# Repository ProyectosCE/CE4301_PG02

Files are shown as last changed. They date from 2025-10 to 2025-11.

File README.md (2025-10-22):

# Instituto Tecnológico de Costa Rica

## Proyecto Grupal 2

### Robot basado en microcontrolador  

#### Arquitectura de Computadores I (CE4301)

---

### Estudiantes

* José Bernardo Barquero Bonilla (2023150476)
* Jose Eduardo Campos Salazar (2023135620)
* Jimmy Feng Feng (2023060347)
* Alexander Montero Vargas (2023166058)

### Profesor

* Dr.-Ing. Jeferson González Gómez — *[jgonzalez@itcr.ac.cr](mailto:jgonzalez@itcr.ac.cr)*

---

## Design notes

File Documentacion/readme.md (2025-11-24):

# **GimmiCoin – Alcancía Inteligente (Proyecto CE4301)**
## *Robot basado en microcontrolador – Arquitectura de Computadores I*

GimmiCoin es un robot–alcancía que detecta monedas por contacto metálico, pesa cada moneda para clasificarla, reproduce un sonido y registra el total acumulado.  
Ofrece una interfaz web embebida accesible desde cualquier teléfono mediante WiFi.

---

# **1. Propósito del Proyecto**
Este proyecto implementa un sistema embebido basado en microcontrolador que permite registrar monedas mediante:

- **Detección por contacto metálico** (flanco limpio y confiable).  
- **Pesaje preciso** mediante celda de carga + HX711.  
- **Movimiento mecánico** mediante motor DC para despejar la bandeja.  
- **Reproducción de audio** con DFPlayer Mini + parlante.  
- **Persistencia** del total mediante EEPROM.  
- **Interfaz web** en modo Access Point con página principal y panel administrativo.

El diseño físico utiliza el personaje Pokémon **Gimmighoul**, integrando electrónica, mecánica y software embebido.

---

# **2. Arquitectura General del Sistema**

Moneda → Sensor de contacto → FSM → Pesaje (HX711)
→ Motor DC (limpieza) → DFPlayer (audio)
→ EEPROM (contador) → WiFi AP → Interfaz Web

El sistema opera como access point (`SoftAP`), donde cualquier smartphone puede conectarse a la red creada por el dispositivo, visualizar el total y gestionar la alcancía.

---

# **3. Hardware Utilizado**

## 3.1 **Componentes principales**
- **Microcontrolador:** ESP8266 (D1 Mini).  
- **Sensor de moneda:** contacto metálico (pull-down externo de 10 kΩ).  
- **Pesaje:** celda de carga TAL221 + amplificador HX711.  
- **Actuador:** motor DC controlado por transistor 2N2222 + diodo flyback.  
- **Audio:** DFPlayer Mini + parlante 8Ω 0.5 W.  
- **Alimentación:** powerbank 5V.  
- **Tarjeta perforada:** montaje final obligatorio.

## 3.2 **Conexiones (resumen)**
- Sensor moneda → `D2`  
- HX711 DT / SCK → `D5 / D6`  
- Motor DC → `D8`  
- DFPlayer Mini → `D3 (TX)` y `D4 (RX con resistencia serie 1 kΩ)`  
- Powerbank 5V → Motor + DFPlayer + regulador interno 3.3V para ESP8266  

---

# **4. Diagrama Eléctrico**

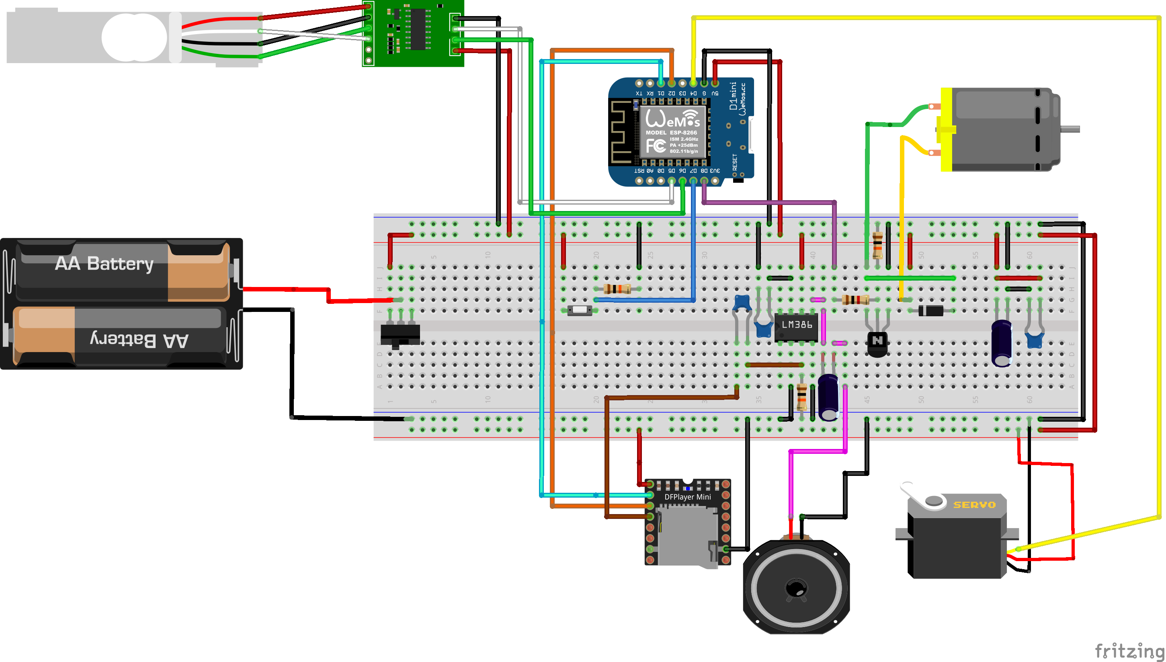
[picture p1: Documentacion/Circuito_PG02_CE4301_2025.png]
Diagrama eléctrico


---

# **5. Máquina de Estados (FSM)**

```mermaid
stateDiagram-v2
    [*] --> DeepSleep

    state "Deep Sleep" as DeepSleep
    state "Wake / Init" as WakeInit
    state "Detección de moneda" as Detect
    state "Pesaje (HX711)" as Weigh
    state "Acciones (motor / audio)" as Actions
    state "Actualizar EEPROM" as UpdateEEPROM
    state "Esperar otra moneda" as WaitCoin
    state "Pre-sleep" as PreSleep

    DeepSleep --> WakeInit: Flanco sensor contacto\n(reset / wakeup)
    WakeInit --> Detect: Init balanza / DFPlayer /\nrestaurar contador
    Detect --> Weigh: Moneda validada
    Weigh --> Actions: Peso estable y válido
    Actions --> UpdateEEPROM: Acción completada
    UpdateEEPROM --> WaitCoin: Guardar total si corresponde

    WaitCoin --> Detect: Nueva moneda antes de timeout
    WaitCoin --> PreSleep: Timeout sin monedas

    PreSleep --> DeepSleep: Preparar deep sleep\n(guardar estado mínimo)

```

---

# **6. Persistencia**

* El total acumulado se almacena en EEPROM.
* Se escribe solo después de un **timeout de 12 s** para evitar desgaste.
* En reinicio o wake del deep sleep, el sistema restaura el total anterior.

---

# **7. Interfaz Web (HTTP sobre WiFi AP)**

## Red generada por el robot:

* **SSID:** `GimmiCoin_AP`
* **Password:** `12345678`
* **IP:** `192.168.4.1`

## Endpoints

| Ruta | Método | Autenticación | Función |
| --- | --- | --- | --- |
| `/` | GET | No | Página principal con total |
| `/estado` | GET | No | JSON con total y estado |
| `/admin`  | GET | Sí | Panel administrativo |
| `/reset`  | GET | Sí | Reinicia contador |

Ejemplo `/estado`:

```json
{
  "total_crc": 350,
  "peso_ultimo": 10.1,
  "moneda_valida": true
}
```

---

# **8. Compilación y Ejecución**

## 8.1 **Requisitos**

Instalar en Arduino IDE / PlatformIO:

* ESP8266 Core
* Librerías:

  * `ESP8266WiFi.h`
  * `ESP8266WebServer.h`
  * `EEPROM.h`
  * `SoftwareSerial.h`
  * `DFRobotDFPlayerMini.h`
  * `HX711.h`

## 8.2 **Configuración**

* Placa: **Wemos D1 Mini**
* Velocidad: **80 MHz**
* Flash size: **4 MB (FS: 1 MB)**
* Baud: **115200**

## 8.3 **Ejecución**

1. Conectar la D1 mini por USB.
2. Seleccionar placa + puerto.
3. Subir firmware.
4. Desconectar USB → alimentar desde powerbank.
5. Conectarse al AP WiFi y abrir:
   [https://192.168.4.1](https://192.168.4.1)

---

# **9. Montaje Mecánico**

* Cuerpo construido como Gimmighoul.
* Bandeja de pesaje alineada con la celda TAL221.
* Motor DC fijo en canal de expulsión.
* Sensor de contacto ubicado en entrada de moneda.
* Placa perforada montada en compartimento seguro.

---

# **10. Lista de Materiales (BOM resumida)**

> Ver archivo completo en `docs/BOM.md`.

| Categoría | Componentes |
| --- | --- |
| MCU | D1 Mini ESP8266 |
| Sensores | Celda TAL221, HX711, sensor de contacto |
| Actuadores | Motor DC + 2N2222 + diodo 1N4148 |
| Audio | DFPlayer Mini + parlante |
| Alimentación | Powerbank 5V |
| Estructura | Materiales 3D o reciclados |
| Otros | Resistencias, cables, placa perforada |

---

# **11. Pruebas Realizadas**

* Pruebas de detección (sensor contacto vs rebotes).
* Pruebas de pesaje y calibración.
* Pruebas motor–expulsión.
* Pruebas audio DFPlayer.
* Pruebas de integración FSM completa.
* Pruebas de interfaz web.
* Pruebas de funcionamiento alimentado por powerbank.

---

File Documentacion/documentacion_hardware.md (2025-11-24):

# Diseño de Hardware – GimmiCoin (Alcancía Inteligente)

## 1. Selección y Justificación del Microcontrolador

El sistema GimmiCoin está basado en el **SoC ESP8266**, utilizando el módulo **D1 Mini** como plataforma de integración. La elección de este microcontrolador se justifica por las siguientes razones:

- **Conectividad Wi-Fi integrada:** permite implementar un servidor web embebido y operar en modo *Access Point* sin hardware adicional de red.
- **Capacidad de cómputo adecuada:** el ESP8266 ofrece recursos suficientes para:
  - Manejar interrupciones del sensor de moneda.
  - Leer y filtrar datos del módulo **HX711**.
  - Controlar el **motor DC** para la limpieza de monedas.
  - Gestionar la comunicación HTTP con la interfaz web.
- **Ecosistema maduro de librerías:** existen librerías probadas para:
  - Servidor web (`ESP8266WebServer`).
  - Manejo de EEPROM.
  - Integración con el módulo **HX711**.
  - Control del módulo de audio **DFPlayer Mini**.
- **Factor de forma compacto:** el D1 Mini tiene un tamaño reducido, lo cual facilita su integración dentro de la estructura física del personaje Gimmighoul.
- **Regulación de 3.3 V integrada:** el propio módulo incorpora regulación a 3.3 V desde 5 V, simplificando el diseño de alimentación cuando se usa una *powerbank* como fuente.

En el montaje final sobre **tarjeta perforada**, se replica el esquema de conexiones del D1 Mini con el resto de componentes, respetando niveles lógicos de 3.3 V y una distribución física adecuada para minimizar ruido y cableado excesivo.

---

## 2. Diagrama Eléctrico General del Sistema

El circuito completo del sistema se modeló y verificó en **Fritzing**. A continuación se muestra el diagrama eléctrico utilizado como referencia para el montaje en tarjeta perforada:

Diagrama eléctrico del sistema

---

## 3. Sensores y Estrategia de Medición

### 3.1 Sensor de Moneda por Contacto

Para la detección básica de la inserción de una moneda se utiliza un **sensor de contacto metálico**:

* Implementado como un par de conductores metálicos que se cierran cuando la moneda pasa por el canal de entrada.
* Un extremo se conecta a **Vcc** (a través de adecuadas resistencias si se requiere) y el otro al pin digital configurado con un **pull-down** externo de 10 kΩ.
* El pin del ESP8266 (por ejemplo **D2**) se configura como entrada digital, leyendo un flanco limpio (paso de **NO contacto → contacto**) que dispara la lógica de conteo y pesaje.
* La detección se complementa con lógica de *debounce* por tiempo en firmware para evitar múltiples detecciones por una misma moneda.

Este sensor permite un disparo confiable del flujo de la FSM sin requerir sensores ópticos adicionales.

### 3.2 Celda de Carga TAL221 + HX711

La **celda de carga TAL221 (100 g)** se utiliza para obtener el peso de la moneda y con ello inferir su denominación:

* La celda funciona como un puente de Wheatstone de 4 hilos, que se conecta al módulo **HX711**.
* El HX711 amplifica la señal analógica de la celda y la convierte a digital mediante un ADC de 24 bits.
* Conexión típica al ESP8266:

  * `DT` → pin digital (ej. **D5**).
  * `SCK` → pin digital (ej. **D6**).
  * `VCC` → 3.3 V.
  * `GND` → GND común.
* En firmware se realiza:

  * Secuencia de *tare* al iniciar el sistema (con la balanza vacía).
  * Lectura de múltiples muestras y promediado para obtener un peso estable.
  * Comparación del peso con rangos predefinidos para clasificar el tipo de moneda (p. ej. ~2.2 g, ~3.5 g, ~7.0 g, ~10.1 g).

Esta estrategia permite distinguir monedas con diámetros similares pero pesos diferentes, mejorando la confiabilidad en la clasificación.

---

## 4. Actuadores y Etapa de Potencia

### 4.1 Motor DC para Limpieza de Monedas

El sistema emplea un **motor DC** como único actuador mecánico para:

* Desplazar la moneda fuera de la zona de pesaje una vez completida la lectura de peso.
* Evitar acumulación de monedas sobre la celda, lo que podría causar errores de medición.

El motor se controla mediante un **transistor NPN 2N2222** en configuración de conmutación:

* **Base**: conectada a un pin digital (por ejemplo **D8**) mediante una resistencia en serie (ej. 1 kΩ).
* **Colector**: al terminal negativo del motor.
* **Emisor**: a GND.
* El terminal positivo del motor se conecta directamente a la línea de **5 V** de la powerbank.
* En paralelo con el motor se coloca un **diodo flyback** (ej. 1N4148 o 1N4007) para proteger contra picos de tensión inducidos al apagar el motor.

Este arreglo forma una etapa de potencia sencilla y adecuada para el consumo típico del motor, aprovechando la capacidad de corriente de la powerbank.

---

## 5. Módulo de Audio: DFPlayer Mini + Parlante

Para la retroalimentación sonora al usuario se utiliza un **DFPlayer Mini**, controlado desde el ESP8266:

* Comunicación mediante UART:

  * `TX` del ESP8266 → `RX` del DFPlayer (a través de una **resistencia serie de 1 kΩ** para adaptar niveles y proteger la entrada).
  * `RX` del ESP8266 → `TX` del DFPlayer (según diseño y disponibilidad de pines).
* Alimentación:

  * `VCC` → 5 V (desde la powerbank).
  * `GND` → GND común.
* El módulo se conecta a un **parlante de 8 Ω / 0.5 W**, suficiente para reproducir efectos de sonido al registrar monedas.

---

## 6. Alimentación y Distribución de Energía

La alimentación del sistema se basa en una **powerbank de 5 V**:

* El **D1 Mini** integra un regulador a 3.3 V, por lo que puede alimentarse directamente desde los 5 V de la powerbank.
* El motor DC y el DFPlayer Mini se alimentan también desde la línea de **5 V**.
* El módulo HX711 se alimenta desde la línea de **3.3 V** del D1 Mini, compartiendo GND común.

---

## 7. Consumo Energético Estimado

El consumo estimado de cada bloque es:

| Componente | Consumo aproximado |
| --- | --- |
| ESP8266 (D1 Mini) | 70–200 mA (según WiFi y carga) |
| HX711 + celda de carga | ~10 mA |
| DFPlayer Mini + parlante | 40–100 mA (según volumen) |
| Motor DC | 150–300 mA (ráfagas cortas) |

En operación típica, el consumo promedio se mantiene dentro de la capacidad de salida de una powerbank estándar (5 V, 2–3 A), permitiendo sesiones prolongadas de uso. La activación del motor DC ocurre solo durante breves intervalos después de cada moneda, lo que reduce su impacto en el consumo medio.

---

## 8. Tarjeta Perforada y Organización Física

Todo el circuito se implementa sobre una **tarjeta perforada** en la versión final del proyecto, cumpliendo con la especificación del curso:

* Se ubican el D1 Mini, el módulo HX711, el transistor 2N2222, el diodo flyback, las resistencias y conectores hacia el motor, sensor de contacto, DFPlayer y parlante.
* Se organizan las pistas de alimentación (5 V y GND) en rieles bien definidos para reducir la cantidad de cables sueltos.
* Las señales sensibles (DT/SCK del HX711 y la línea del sensor de contacto) se mantienen separadas del cableado del motor para minimizar el ruido.
* Se utilizan conectores o headers desmontables para facilitar el montaje y mantenimiento dentro de la estructura del Gimmighoul.

---

## 9. Consideraciones de Diseño Mecánico

El chasis del proyecto se basa en la estética del personaje **Gimmighoul**:

* La **bandeja de pesaje** se monta rígidamente sobre la celda TAL221, de forma que solo las fuerzas verticales de la moneda sean transmitidas a la celda.
* El **motor DC** y su mecanismo (por ejemplo, una paleta/plataforma que empuja la moneda) se alinean con la salida de la bandeja para que todas las monedas abandonen la zona de medición.
* El **sensor de contacto** se ubica en la entrada de monedas, garantizando que cualquier moneda deba cerrar el circuito para ser detectada.
* Se reserva un compartimento aislado para:

  * Powerbank.
  * Tarjeta perforada.
  * Cableado.
  * DFPlayer y parlante.
* Se evita el contacto directo de las monedas con la electrónica para prevenir cortocircuitos y daños por suciedad o humedad.

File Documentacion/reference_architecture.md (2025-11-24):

# Arquitectura de Referencia – GimmiCoin (Gimmighoul Coin Collector)

---

## 1. Resumen del Sistema

GimmiCoin es una **alcancía inteligente** basada en un microcontrolador **ESP8266 (D1 Mini)** que:

1. Detecta monedas mediante un **sensor de contacto metálico**.
2. Pesa la moneda usando una **celda de carga TAL221 + módulo HX711**.
3. Acciona un **motor DC** para desplazar la moneda fuera de la bandeja de pesaje.
4. Reproduce un sonido con un **DFPlayer Mini** + parlante.
5. Actualiza un **contador total** almacenado en EEPROM.
6. Expone el estado mediante una **aplicación web** servida por el ESP8266 en modo **Access Point (AP)**.

La arquitectura de referencia define cómo se organizan estos componentes de hardware y software, así como los flujos principales y las interfaces entre ellos.

---

## 2. Objetivos Arquitectónicos

Los principales objetivos de diseño son:

- **Simplicidad y robustez:** Minimizar la cantidad de actuadores y sensores mecánicamente complejos. Se usa un solo motor DC y un sensor de contacto simple.
- **Medición confiable:** Usar **peso** en lugar de geometría para distinguir monedas con diámetros similares.
- **Bajo acoplamiento:** Separar hardware, firmware y aplicación web en módulos bien definidos.
- **Escalabilidad:** Permitir futuras mejoras (clasificación por tipo de moneda, más vistas en la app, integración con backend externo).
- **Trazabilidad ágil:** Mantener una arquitectura que se refleje directamente en el **Product Backlog**, la **Definition of Done (DoD)** y el **Risk Assessment**.

---

## 3. Arquitectura de Hardware (Vista de Bloques)

### 3.1 Diagrama de bloques de hardware

```mermaid
flowchart LR
    subgraph PWR[Alimentación]
        PB[Powerbank 5V]
    end

    subgraph MCU[D1 Mini – ESP8266]
        CPU[Firmware FSM<br/>WiFi AP + HTTP]
        MEM[EEPROM / Flash<br/>contador total]
    end

    SC[Sensor de contacto<br/>moneda]
    LC[Celda de carga TAL221<br/>100 g]
    HX[HX711<br/>ADC 24 bits]
    MOT[Motor DC<br/>desplazamiento moneda]
    NPN[2N2222 + diodo<br/>etapa de potencia]
    DF[DFPlayer Mini]
    SPK[Parlante 8Ω 0.5W]

    %% Conexiones de señal
    SC -->|GPIO digital| MCU
    LC --- HX
    HX -->|DT, SCK| MCU
    MCU -->|GPIO| NPN
    NPN --> MOT
    MCU <-->|UART| DF
    DF --- SPK

    %% Alimentación
    PB -->|5V| MCU
    PB -->|5V| MOT
    PB -->|5V| DF
```

### 3.2 Justificación de decisiones de hardware

* **Powerbank 5 V:**
  Simplifica la alimentación (no se requiere etapa LiPo + cargador + boost/buck separados). Además, las powerbanks son fáciles de recargar y proporcionan corriente suficiente para el motor y DFPlayer.

* **Sensor de contacto:**
  Es una solución simple y confiable para detectar el paso de monedas, sin necesidad de sensor IR ni óptico. Facilita el montaje mecánico y reduce costos.

* **Celda de carga + HX711:**
  Permite diferenciar monedas por peso con buena resolución. El HX711 provee una interfaz digital síncrona sencilla de manejar desde el ESP8266.

* **Motor DC + 2N2222:**
  Un solo actuador mecánico es suficiente para despejar la bandeja. La etapa de potencia con 2N2222 + diodo flyback es una solución estándar y robusta.

* **DFPlayer Mini + parlante:**
  Descentraliza el manejo de audio (el ESP8266 solo envía comandos por UART), reduciendo la carga de procesamiento y memoria del microcontrolador.

---

## 4. Arquitectura del Software Embebido

La arquitectura de software se organiza en tres capas principales:

1. **Drivers / HAL (Hardware Abstraction Layer)**
2. **Servicios de dominio (lógica de GimmiCoin)**
3. **Capa de aplicación y comunicación (FSM + HTTP)**

### 4.1 Diagrama de capas de software

```mermaid
flowchart TD
    subgraph APP[Capa de Aplicación]
        FSM[FSM de GimmiCoin<br/>DeepSleep, Detect, Weigh,<br/>Actions, UpdateEEPROM, Wait, PreSleep]
        HTTP[Servidor HTTP<br/>/ /estado /admin /reset]
    end

    subgraph SRV[Servicios]
        DET[Servicio de detección de moneda]
        WEI[Servicio de pesaje y filtrado]
        ACT[Servicio de acciones<br/>motor + audio]
        PERS[Servicio de persistencia<br/>EEPROM]
        NET[Servicio de red<br/>WiFi AP]
    end

    subgraph DRV[Drivers / HAL]
        D_GPIO[Driver GPIO<br/>sensor, motor]
        D_HX[Driver HX711]
        D_DFP[Driver DFPlayer]
        D_EE[Driver EEPROM]
        D_WIFI[Driver WiFi / TCP]
    end

    FSM --> DET
    FSM --> WEI
    FSM --> ACT
    FSM --> PERS
    HTTP --> NET
    DET --> D_GPIO
    WEI --> D_HX
    ACT --> D_GPIO
    ACT --> D_DFP
    PERS --> D_EE
    NET --> D_WIFI
```

### 4.2 Relación con módulos `.ino`

* `GimmiCoin_Main.ino` → FSM + inicialización.
* `GimmiCoin_SensorMoneda.ino` → parte de **DET + D_GPIO**.
* `GimmiCoin_Balanza.ino` → **WEI + D_HX**.
* `GimmiCoin_Motor.ino` → **ACT + D_GPIO**.
* `GimmiCoin_Sonido.ino` → **ACT + D_DFP**.
* `GimmiCoin_Memoria.ino` → **PERS + D_EE**.
* `GimmiCoin_Web.ino` → **HTTP + NET + D_WIFI**.

Este mapeo permite vincular directamente el **Product Backlog** con componentes arquitectónicos concretos (por ejemplo, historias de usuario para el servicio de pesaje, o para la interfaz web).

---

## 5. Arquitectura de Comunicación y Aplicación Web

El modelo de comunicación es **cliente–servidor** sobre HTTP dentro de una red local creada por el propio robot.

### 5.1 Diagrama de bloques de comunicación

```mermaid
flowchart TD
    C[Teléfono / Laptop<br/> Cliente Web] <--> S[ESP8266<br/>AP + Servidor HTTP]

    S --> H[HTML - Página principal<br/>GET /]
    S --> J[JSON de estado<br/>GET /estado]
    S --> A[Panel admin<br/>GET /admin]
    S --> R[Comando RESET<br/>GET /reset]
```

### 5.2 Diagrama de secuencia – Lectura de estado

```mermaid
sequenceDiagram
    participant User as Cliente Web
    participant HTTP as ESP8266 HTTP
    participant FSM as FSM / Servicios

    User->>HTTP: GET /estado
    HTTP->>FSM: Solicitar estado actual
    FSM-->>HTTP: total_crc, peso_ultimo, moneda_valida
    HTTP-->>User: JSON { total_crc, peso_ultimo, moneda_valida }
    User->>User: Refresca UI
```

### 5.3 Diagrama de secuencia – Reset desde el panel admin

```mermaid
sequenceDiagram
    participant Admin as Cliente (Admin)
    participant HTTP as ESP8266 HTTP
    participant MEM as EEPROM / Persistencia

    Admin->>HTTP: GET /reset (Basic Auth)
    HTTP->>MEM: Escribir total_crc = 0
    MEM-->>HTTP: Confirmación de escritura
    HTTP-->>Admin: JSON { "status": "ok", "reset": true }
```

---

## 6. Máquina de Estados de Alto Nivel (FSM)

La FSM coordina el comportamiento global del sistema, integrando sensores, acciones, persistencia y deep sleep.

```mermaid
stateDiagram-v2
    [*] --> DeepSleep

    state "Deep Sleep" as DeepSleep
    state "Wake / Init" as WakeInit
    state "Detección de moneda" as Detect
    state "Pesaje (HX711)" as Weigh
    state "Acciones (motor / audio)" as Actions
    state "Actualizar EEPROM" as UpdateEEPROM
    state "Esperar otra moneda" as WaitCoin
    state "Pre-sleep" as PreSleep

    DeepSleep --> WakeInit: Wake por sensor / reset
    WakeInit --> Detect: Init pines / HX711 /\nDFPlayer / WiFi AP
    Detect --> Weigh: Moneda detectada\n(bandera ISR)
    Weigh --> Actions: Peso estable\ny moneda válida
    Actions --> UpdateEEPROM: Motor + sonido OK
    UpdateEEPROM --> WaitCoin: Guardar total\n(si timeout cumplido)

    WaitCoin --> Detect: Nueva moneda\nantes del timeout
    WaitCoin --> PreSleep: Sin monedas\npor T_TIMEOUT

    PreSleep --> DeepSleep: Guardar estado mínimo\n+ entrar a deep sleep
```

---

## 7. Relación con Metodología Ágil

La arquitectura de referencia sirvió como base para:

* **Product Backlog:**

  * Historias de usuario ligadas a bloques arquitectónicos:

    * HU: “Como usuario quiero ver el total ahorrado en mi teléfono” → módulo HTTP + servicios NET + PERS.
    * HU: “Como usuario quiero que la alcancía reconozca monedas automáticamente” → DET + WEI + FSM.
    * HU: “Como administrador quiero resetear el contador” → HTTP `/admin` + `/reset` + PERS.

* **Definition of Done (DoD):**

  * Cada historia de usuario se considera terminada cuando:

    * Está integrada en la FSM y en el bloque arquitectónico correspondiente.
    * Se verifican pruebas unitarias/integración sobre las rutas HTTP, pesaje, detección y motor.

* **Risk Assessment:**

  * Los riesgos críticos (por ejemplo, calibración de peso, ruido eléctrico, integración física) se mapean a componentes:

    * R9 (calibración) → bloque WEI + D_HX.
    * R2 (alimentación) → bloque PWR + MOT + DFPlayer.
    * R7 (integración física) → interacción entre hardware mecánico (LC, MOT) y comp. electrónicos.

* **Planificación por Sprints:**

  * Sprint 1: Sensado de moneda (DET), prototipo de pesaje (WEI) y servidor web mínimo.
  * Sprint 2: FSM completa, integración motor + DFPlayer (ACT).
  * Sprint 3: Deep sleep, refinamiento de UI y calibración de peso.
  * Sprint 4: Pruebas finales, documentación y video de demostración.

De esta forma, la arquitectura no es solo un diagrama estático, sino una **guía para el desarrollo ágil**, que permite priorizar, estimar esfuerzo y evaluar el progreso de forma continua.

---

## 8. Seguridad y Robustez

La arquitectura contempló desde el inicio aspectos de:

* **Seguridad eléctrica:**

  * Uso de diodo flyback en motor.
  * Desacoplo en 5 V y 3.3 V.
  * GND común y rutas separadas para señales sensibles.
* **Seguridad lógica:**

  * Autenticación básica en `/admin` y `/reset`.
  * Validación de entradas del cliente (por ejemplo, impedir montos negativos).
* **Robustez de firmware:**

  * ISR corta para el sensor de contacto.
  * Promediado de lecturas de HX711 para evitar ruido.
  * Escrituras diferidas en EEPROM para reducir desgaste.

---

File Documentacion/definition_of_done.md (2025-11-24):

# Definition of Done (DoD) – Proyecto GimmiCoin

---

## 1. Propósito

La *Definition of Done* (DoD) define los criterios concretos que se deben cumplir para considerar que:

- Una **funcionalidad**,  
- Un **módulo** de hardware/firmware,  
- O un **entregable** del proyecto  

están **completamente terminados** y listos para demostración / defensa.

La DoD aplica a todos los subsistemas:

- Hardware (sensor de contacto, celda de carga + HX711, motor DC, DFPlayer, powerbank, perforada).  
- Firmware (FSM, lectura de sensores, control de actuadores, EEPROM).  
- Aplicación web (AP WiFi, endpoints HTTP, UI).  
- Documentación (repositorio, diagramas, pruebas, video).

---

## 2. Criterios Generales de Finalización

Una historia de usuario, tarea o issue se considera **DONE** cuando:

1. El **código compila sin errores** y el firmware corre de forma estable en el ESP8266.  
2. El módulo de hardware está **correctamente cableado y probado** de forma independiente.  
3. Se han realizado **pruebas unitarias** o de integración que verifiquen el comportamiento esperado.  
4. La funcionalidad está **integrada en la FSM** y no rompe otros estados o flujos.  
5. Se ha actualizado la **documentación correspondiente** en el repositorio (`/docs`, `README`, comentarios de código, etc.).  
6. Existen **evidencias** (fotos, capturas de la web, videos cortos o salidas por puerto serial) vinculadas al issue.  
7. Al menos un miembro distinto del autor ha **revisado y aprobado** los cambios (revisión de código / pruebas en hardware).  
8. La tarea o issue aparece en GitHub como **Closed**, con una referencia a la rama / commit asociado.  

> Ninguna tarea se considera *DONE* solo porque “funciona en mi máquina”: debe pasar por integración, documentación mínima y evidencias.

---

## 3. Criterios Específicos por Subsistema

### 3.1 Firmware (FSM y lógica de control)

La parte de firmware se considera **terminada** cuando:

- La **FSM** implementa todos los estados definidos:  
  `DeepSleep`, `WakeInit`, `Detect`, `Weigh`, `Actions`, `UpdateEEPROM`, `WaitCoin`, `PreSleep`.  
- Se han probado **todas las transiciones** relevantes:
  - Inserción de moneda simple.  
  - Inserción de varias monedas seguidas.  
  - Timeout sin monedas (paso a `PreSleep` y luego `DeepSleep`).  
- El **código está modularizado** en los archivos `.ino` acordados:
  - `GimmiCoin_Main.ino` (setup, loop, FSM).  
  - `GimmiCoin_SensorMoneda.ino` (detección).  
  - `GimmiCoin_Balanza.ino` (HX711).  
  - `GimmiCoin_Motor.ino` (motor DC).  
  - `GimmiCoin_Sonido.ino` (DFPlayer).  
  - `GimmiCoin_Memoria.ino` (EEPROM).  
  - `GimmiCoin_Web.ino` (AP + HTTP).  
- No hay **bloqueos** ni reinicios inesperados durante al menos:
  - 10 ciclos completos de inserción de moneda → pesaje → motor → sonido → actualización.

---

### 3.2 Sensado de Moneda (Sensor de contacto)

El subsistema de **detección de moneda** se considera DONE cuando:

- El sensor de contacto está correctamente instalado en el canal de entrada de monedas.  
- El pin del ESP8266:
  - Está configurado como entrada digital con **pull-down externo** de 10 kΩ.  
  - Genera una interrupción (ISR) ante el flanco configurado.  
- La ISR:
  - Es **muy corta** (solo marca una bandera y registra `micros()`).  
  - Implementa un **debounce por tiempo** (`MIN_PULSE_INTERVAL`) para evitar rebotes.  
- La FSM solo procesa **una detección por moneda**, incluso cuando la moneda rebota mecánicamente.  
- En pruebas con al menos 20 monedas:
  - La tasa de detecciones falsas (sin moneda) es ~0%.  
  - La tasa de monedas perdidas es ≤ 5%.

---

### 3.3 Pesaje y Clasificación (Celda de carga + HX711)

El subsistema de **pesaje** se considera DONE cuando:

- La celda TAL221 está firmemente montada en la estructura del Gimmighoul, sin juego lateral excesivo.  
- El módulo HX711:
  - Está correctamente cableado (DT/SCK a pines del D1 Mini, VCC 3.3 V, GND común).  
  - Usa una frecuencia de muestreo estable (10–80 SPS).  
- Se realizó una **calibración documentada**:
  - Incluye factores de conversión de lectura cruda → gramos.  
  - Usa al menos dos pesos de referencia (monedas reales).  
- La función de lectura:
  - Promedia varias muestras (`N ≥ 10`).  
  - Aplica filtros básicos (por ejemplo, descartar outliers).  
- La clasificación:
  - Define rangos de peso claros para cada tipo de moneda soportada.  
  - Se probó con al menos 5 lecturas por tipo de moneda.  

Estado objetivo: **error de clasificación ≤ 5–10 %** en pruebas controladas.

---

### 3.4 Acciones Físicas: Motor DC

El subsistema del **motor DC** se considera DONE cuando:

- El motor está montado en la estructura de forma que:
  - Despeje completamente la moneda de la plataforma de pesaje.  
  - No interfiera físicamente con el sensor ni con la celda.  
- La etapa de potencia con **2N2222 + diodo flyback**:
  - Presenta conexiones correctas (base, colector, emisor, motor, diodo).  
  - Usa una resistencia base adecuada (por ejemplo 1 kΩ).  
- El firmware:
  - Implementa una función `motor_pulse(T_MOTOR_MS)` o equivalente.  
  - Garantiza que el motor se enciende por el tiempo correcto y luego se apaga.  
- En pruebas de ≥ 20 ciclos:
  - El motor no provoca reset del ESP8266.  
  - No induce errores severos en la lectura de la balanza (se lee solo con el motor apagado).  

---

### 3.5 Audio (DFPlayer Mini + Parlante)

El subsistema de **audio** se considera DONE cuando:

- El DFPlayer está correctamente cableado:
  - Alimentación a 5 V de la powerbank.  
  - GND común con el resto del sistema.  
  - Línea RX protegida con resistencia serie (≈1 kΩ).  
- La tarjeta microSD:
  - Contiene al menos un archivo `.mp3` correctamente numerado.  
- El firmware:
  - Inicializa el DFPlayer con un retardo suficiente (≥ 1200 ms).  
  - Permite reproducir el sonido de forma confiable ante cada moneda válida.  
- En pruebas de 20 monedas:
  - El sonido se reproduce > 90 % de las veces.  
  - No se escuchan artefactos graves por falta de alimentación (distorsión fuerte).  

---

### 3.6 Alimentación (Powerbank 5 V)

La **alimentación** del sistema se considera DONE cuando:

- El robot opera completamente desde una **powerbank de 5 V**, sin estar conectado al USB de la PC.  
- Se midieron aproximaciones de consumo en:
  - Reposo (sin monedas).  
  - Durante motores y DFPlayer.  
- No se presentan resets o parpadeos extraños al activar el motor o reproducir audio.  
- La autonomía demostrada es razonable para el uso esperado (por ejemplo, ≥ 30 minutos de uso continuo en demostración).

---

### 3.7 Persistencia (EEPROM / Flash)

El subsistema de **memoria persistente** se considera DONE cuando:

- El total acumulado (en colones o equivalentes) se guarda en EEPROM / Flash.  
- Se implementa una **estrategia de escritura diferida**:
  - Solo se escribe después de un tiempo sin nuevas monedas (ej. 12 s).  
  - Durante la inserción frecuente de monedas, solo se actualiza en RAM.  
- Al reiniciar el dispositivo:
  - El total se restaura correctamente desde EEPROM.  
- Se verificó que:
  - No se escribe en EEPROM en cada moneda.  
  - El número de escrituras se mantiene razonable frente a la vida útil estimada.

---

### 3.8 Aplicación Web y Comunicación WiFi

La **aplicación web** se considera DONE cuando:

- El ESP8266 crea un **Access Point** con SSID y password definidos.  
- Un teléfono o laptop puede:
  - Conectarse al AP.  
  - Abrir la URL `http://192.168.4.1/`.  
- Se implementan los endpoints:
  - `/` (HTML principal).  
  - `/estado` (JSON).  
  - `/admin` (panel admin, Basic Auth).  
  - `/reset` (reseteo del contador, Basic Auth).  
- La interfaz:
  - Muestra el total acumulado y el estado del sistema.  
  - Se actualiza periódicamente (por ejemplo, usando `fetch('/estado')` con `setInterval`).  
- La función de `reset`:
  - Reinicia el contador a 0.  
  - Actualiza EEPROM correctamente.  

Debe existir evidencia de uso real:
- Capturas de pantalla desde un teléfono.  
- Pruebas de conexión y reconexión sin cuelgues.

---

### 3.9 Estructura Física y Perforada

La parte **física** se considera DONE cuando:

- Todo el circuito electrónico está montado en una **tarjeta perforada** o PCB.  
- No hay conexiones sueltas o puentes temporales sobre protoboard.  
- El montaje mecánico dentro del Gimmighoul:
  - Permite cerrar la estructura.  
  - Protege la electrónica de contacto directo con las monedas.  
- Se cuenta con:
  - Fotografías del montaje interno.  
  - Fotografías del robot completo.

---

### 3.10 Documentación y Repositorio

La documentación se considera DONE cuando:

- El repositorio Git contiene:
  - `README.md` completo y actualizado.  
  - Carpeta `/docs` con:
    - Arquitectura hardware y software.  
    - Aplicación de usuario.  
    - BOM.  
    - Risk Assessment.  
    - Definition of Done (este documento).  
- Existen:
  - Diagramas en **Mermaid** o imágenes claras (diagramas de bloques, FSM).  
  - Evidencias de pruebas (fotos, capturas, video de demo).  
- Los issues principales están:
  - Cerrados.  
  - Enlazados a commits o Pull Requests.

---

## 4. Validación Final del Proyecto

El proyecto GimmiCoin se considera **completamente terminado** cuando:

1. Todas las historias de usuario planificadas para el alcance del curso están marcadas como DONE según los criterios anteriores.  
2. El robot:
   - Detecta monedas por contacto.  
   - Las pesa y clasifica correctamente (según calibres definidos).  
   - Acciona el motor para limpiar la bandeja.  
   - Reproduce audio con el DFPlayer.  
3. El total ahorrado puede verse en la aplicación web y se mantiene tras reinicios.  
4. El sistema funciona durante la **demostración completa** sin fallos críticos.  
5. Toda la documentación técnica y de usuario está disponible y sincronizada con el estado real del hardware y firmware.  

---

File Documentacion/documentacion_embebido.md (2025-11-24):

# Arquitectura del Software Embebido – GimmiCoin

## 1. Visión General

El firmware de **GimmiCoin** se ejecuta sobre un **ESP8266 (D1 Mini)** y controla todo el comportamiento de la alcancía inteligente:

- Detección de monedas mediante un **sensor de contacto metálico**.
- Lectura y filtrado de peso con **celda de carga TAL221 + HX711**.
- Accionamiento de un **motor DC** para limpiar la plataforma de pesaje.
- Reproducción de audio con **DFPlayer Mini**.
- Exposición de un **servidor web HTTP** en modo *Access Point*.
- Persistencia del total acumulado en **EEPROM/Flash**.
- Transición a **deep sleep** para ahorrar energía tras un período de inactividad.

El diseño se basa en una **máquina de estados finita (FSM)** que coordina la lógica de alto nivel, apoyada por módulos especializados (.ino) para cada subsistema.

---

## 2. Organización del Firmware

El código fuente se organiza en módulos, cada uno con responsabilidades claras:

- **`GimmiCoin_Main.ino`**
  - `setup()` y `loop()`.
  - Inicialización global de pines, WiFi AP y servidor HTTP.
  - Orquestación de la FSM y llamados a los demás módulos.
- **`GimmiCoin_SensorMoneda.ino`**
  - Configuración del pin del sensor de contacto.
  - Rutina de interrupción (ISR) y lógica de *debounce*.
  - Señales al módulo de FSM cuando hay una nueva moneda.
- **`GimmiCoin_Balanza.ino`**
  - Inicialización del **HX711**.
  - Rutinas de *tare*, lectura múltiple y filtrado.
  - Conversión de lecturas crudas a gramos.
- **`GimmiCoin_Motor.ino`**
  - Control del **motor DC** (encendido/apagado).
  - Aplicación del tiempo de activación (*pulse width*).
- **`GimmiCoin_Sonido.ino`**
  - Inicialización del **DFPlayer Mini**.
  - Funciones para reproducir efectos de sonido al registrar una moneda.
- **`GimmiCoin_Memoria.ino`**
  - Lectura/escritura de valores en EEPROM (por ejemplo, el total acumulado).
  - Estrategia de reducción de escrituras (timeout antes de persistir).
- **`GimmiCoin_Web.ino`**
  - Configuración del **Access Point**.
  - Manejo del servidor HTTP (`/`, `/estado`, `/admin`, `/reset`).
  - Generación de HTML y JSON.

Esta modularización facilita el desarrollo incremental, las pruebas por subsistema y el mantenimiento futuro.

---

## 3. Máquina de Estados (FSM)

El flujo de alto nivel del firmware se modela como una **FSM**. Las transiciones dependen de los eventos del sensor de moneda, la estabilidad del peso, el tiempo de espera y los comandos de la aplicación web.

### 3.1 Estados principales

1. **DeepSleep**  
   - El ESP8266 se encuentra en bajo consumo, esperando un evento externo.
2. **WakeInit**  
   - Inicialización básica: pines, HX711, DFPlayer, servidor web, lectura de total almacenado.
3. **Detect**  
   - Espera de detección de moneda por el sensor de contacto (bandera de ISR).
4. **Weigh**  
   - Lectura del peso con el HX711 y filtrado de muestras.
5. **Actions**  
   - Activación del motor DC y del DFPlayer (movimiento + sonido).
6. **UpdateEEPROM**  
   - Actualización del total en memoria si corresponde.
7. **WaitCoin**  
   - Ventana de tiempo para recibir otra moneda antes de dormir.
8. **PreSleep**  
   - Preparación para entrar nuevamente en `DeepSleep`.

### 3.2 Diagrama de Estados (Mermaid)

```mermaid
stateDiagram-v2
    [*] --> DeepSleep

    state "Deep Sleep" as DeepSleep
    state "Wake / Init" as WakeInit
    state "Detección de moneda" as Detect
    state "Pesaje (HX711)" as Weigh
    state "Acciones (motor / audio)" as Actions
    state "Actualizar EEPROM" as UpdateEEPROM
    state "Esperar otra moneda" as WaitCoin
    state "Pre-sleep" as PreSleep

    DeepSleep --> WakeInit: Wake por sensor / reset
    WakeInit --> Detect: Init HX711 / DFPlayer /\nrestaurar total
    Detect --> Weigh: Moneda detectada\n(bandera ISR)
    Weigh --> Actions: Peso estable y válido
    Actions --> UpdateEEPROM: Movimiento + sonido OK
    UpdateEEPROM --> WaitCoin: Persistir si timeout cumplido

    WaitCoin --> Detect: Nueva moneda\nantes del timeout
    WaitCoin --> PreSleep: Sin monedas\ndurante timeout

    PreSleep --> DeepSleep: Guardar estado mínimo\n+ entrar en deep sleep
````

---

## 4. Flujo del Programa Principal

El flujo general en `GimmiCoin_Main.ino` puede resumirse así:

```cpp
void setup() {
  initPins();
  initSensorMoneda();
  initBalanzaHX711();
  initDFPlayer();
  initWiFiAP();
  initWebServer();
  cargarTotalDesdeEEPROM();
  fsm_setState(WAKE_INIT);
}

void loop() {
  // Atender peticiones HTTP
  web_handleClient();

  // Actualizar FSM
  fsm_update();

  // Otras tareas periódicas (si aplica)
}
```

La función `fsm_update()` revisa el estado actual, procesa los eventos (moneda detectada, peso estable, timeout) y realiza las transiciones correspondientes.

---

## 5. Estrategia de Gestión de E/S

### 5.1 Sensor de moneda – Interrupción

El **sensor de contacto** se usa como disparador principal; se conecta a un pin digital con un **pull-down externo** y se configura para generar una interrupción cuando hay cambio de estado.

* Modo: interrupción por cambio (`CHANGE`) o flanco descendente (`FALLING`), según el diseño final.
* Objetivo: detectar el momento en que la moneda cierra el circuito.
* La lógica pesada (pesaje, sonido, motor) **no se ejecuta en la ISR**, solo se marca una bandera.

Ejemplo simplificado de ISR:

```cpp
volatile bool monedaDetectada = false;
volatile unsigned long lastPulseMicros = 0;
const unsigned long MIN_PULSE_INTERVAL = 300000; // 0.3 s

void IRAM_ATTR isrSensorMoneda() {
  unsigned long now = micros();
  if (now - lastPulseMicros > MIN_PULSE_INTERVAL) {
    monedaDetectada = true;       // Se procesa luego en la FSM
    lastPulseMicros = now;
  }
}
```

En `loop()`, la FSM consulta `monedaDetectada` y, si está activa, la consume y pasa al estado `Weigh`.

### 5.2 Lectura de balanza – Polling controlado

El módulo **HX711** se lee mediante una interfaz sincrónica de 2 hilos (DT/SCK). El acceso se implementa mediante polling controlado:

* La rutina de balanza:

  * Obtiene varias lecturas consecutivas.
  * Descartar outliers.
  * Calcula un promedio.
* El peso final se pasa a la FSM para clasificación por rangos.

Ejemplo de flujo lógico:

```cpp
float leerPesoFiltrado() {
  const int N = 10;
  long suma = 0;
  for (int i = 0; i < N; i++) {
    long lectura = hx711.read();
    suma += lectura;
  }
  long promedio = suma / N;
  return convertirALibrasOGramos(promedio); // según la calibración
}
```

La FSM asegura que el motor no se active hasta que el peso sea estable.

### 5.3 Motor DC – Salida digital

El **motor DC** se controla con un solo pin digital (por ejemplo `D8`), que gobierna la base del 2N2222:

* Una función de alto nivel, por ejemplo `motor_pulse(T_MOTOR_MS)`, se encarga de:

  * Activar el pin.
  * Esperar el tiempo necesario.
  * Apagar el pin.

Esta operación se llama desde el estado `Actions` de la FSM.

### 5.4 DFPlayer Mini – UART

El DFPlayer se controla mediante UART (hardware o `SoftwareSerial`):

* Comandos básicos: inicialización, selección de track, volumen y reproducción.
* La capa de servicio (`GimmiCoin_Sonido.ino`) expone funciones como:

```cpp
void sonido_init();
void sonido_reproducirMoneda();
```

Estas se invocan desde la FSM en el estado `Actions`.

### 5.5 Servidor Web – HTTP

El servidor HTTP se implementa con `ESP8266WebServer`:

* Se atiende dentro de `loop()` mediante `web_handleClient()`.
* El tiempo de atención es corto para no bloquear la FSM.

---

## 6. Prioridades, Latencias y Sincronización

### 6.1 Prioridades

* **Máxima prioridad:** ISR del sensor de moneda.

  * Debe ser extremadamente corta: solo marcar banderas y tiempos.
* **Segundo nivel:** lectura de balanza (Weigh).

  * Se ejecuta cuando hay moneda detectada; durante este proceso el motor y el DFPlayer se mantienen inactivos.
* **Tercer nivel:** servidor web HTTP.

  * Atiende peticiones entre eventos de la FSM, sin bloquear el flujo principal.
* **Cuarto nivel:** escritura en EEPROM.

  * Se realiza de forma diferida, después de un timeout, para no afectar la respuesta del sistema.

### 6.2 Latencias

* **Detección de moneda:** inmediata (interrupción) con validación de *debounce* por tiempo.
* **Pesaje:** la obtención de un peso estable puede tomar decenas de milisegundos, debido al muestreo múltiple y al tiempo de estabilización mecánica.
* **Acciones (motor y audio):** el tiempo de motor es fijo (`T_MOTOR`), el audio corre en paralelo.

La FSM está diseñada para que:

* El sistema responda rápidamente a la inserción de una moneda.
* No se mezclen acciones de varios eventos de moneda; se procesa una a la vez.

### 6.3 Sincronización

* Variables compartidas entre ISR y programa principal (`monedaDetectada`, `lastPulseMicros`) se declaran como `volatile`.
* La FSM consume y limpia las banderas de evento de manera atómica (o con secciones críticas muy pequeñas si se requiere).
* Las rutinas de EEPROM usan contadores/timers para evitar escrituras excesivas.

---

## 7. Protocolos de Comunicación

### 7.1 Interfaz con HX711 (tipo SPI de 2 hilos)

* El HX711 utiliza una interfaz síncrona de 2 hilos (`DT` y `SCK`).
* El ESP8266 genera los pulsos de reloj en `SCK` y lee datos en `DT`.
* La implementación es *bit-banged* (no se usa el SPI hardware), pero desde el punto de vista de arquitectura se considera un **protocolo digital síncrono**.

### 7.2 UART con DFPlayer

* Comunicación serial asíncrona a 9600 bps.
* Protocolo de comandos propio del DFPlayer (paquetes con encabezados, longitud y checksum).
* Permite controlar la reproducción de pistas de audio almacenadas en la tarjeta microSD.

### 7.3 HTTP sobre WiFi (SoftAP)

* El ESP8266 crea una red **Access Point** (SoftAP).
* Los clientes se conectan con su teléfono o portátil.
* La comunicación se realiza vía HTTP:

  * `GET /` → página HTML con el estado de la alcancía.
  * `GET /estado` → JSON con información para clientes más avanzados.
  * `GET /admin` y `GET /reset` → gestión de la alcancía (protegido).

Esta combinación de protocolos cumple con el requisito del curso de utilizar **múltiples protocolos de comunicación digitales** (UART, interfaz tipo SPI y HTTP sobre WiFi).

---

## 8. Organización de Memoria

### 8.1 RAM

* Variables principales:

  * Contadores de monedas y montos.
  * Estado actual de la FSM.
  * Buffers temporales para lecturas de HX711.
  * Buffers pequeños de strings para HTML/JSON.
* Optimización:

  * Se evita el uso de `String` dinámico en bucles críticos.
  * Se prefiere `String` local de tamaño acotado o cadenas `const char*` almacenadas en flash (`PROGMEM`) cuando es posible.

### 8.2 EEPROM / Flash

* Se usa EEPROM para almacenar:

  * El total acumulado (CRC o colones).
* Estrategia de escritura:

  * Cada vez que se detecta una moneda, se **actualiza el total en RAM**.
  * Un **timeout** (ej. 12 s sin nuevas monedas) dispara la escritura en EEPROM.
  * De esta forma se reducen las escrituras y se alarga la vida útil de la memoria.

### 8.3 Código (Flash)

* El firmware completo se almacena en la flash del ESP8266.
* Las páginas web (HTML, CSS y posible JavaScript ligero) se incrustan como literales de texto en el código:

  * Se usan `R"rawliteral(...)"` para reducir el overhead de concatenaciones.
  * Esto permite servir la interfaz sin necesidad de un sistema de archivos adicional.

---

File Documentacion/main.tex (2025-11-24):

\documentclass[letter,12pt]{article}
\usepackage[left=2.54cm, right=2.54cm, top=2.54cm, bottom=2.54cm]{geometry}
\usepackage{setspace}
\setlength{\parindent}{1.27cm}
\setlength{\parskip}{0pt}
\usepackage{graphicx}
\usepackage{float}
\usepackage{caption}
\usepackage{csquotes}
\usepackage{amsmath}
\usepackage{svg}
\usepackage{indentfirst}

%==========REFERENCIAS=============
\usepackage[backend=bibtex,style=ieee,language=spanish]{biblatex}
\addbibresource{referencias.bib}

\usepackage[
    xetex,
    pdftitle={Proyecto Grupal \#2 - Anteproyecto},
    pdfauthor={Barquero, J., Campos, J., Feng, J., Montero, A.},
    pdfsubject={CE4301 - Arquitectura de Computadores I},
    pdfkeywords={ESP8266, ESP32, sistemas embebidos, proyecto de arquitectura, IoT},
    pdfproducer={LaTeX with hyperref package},
    pdfcreator={pdfLatex}
]{hyperref}

\hypersetup{
    colorlinks=true,
    linkcolor = black,
    urlcolor  = blue,
    citecolor = black,
    anchorcolor = blue
}

\begin{document}

% ====== Portada ======
\begin{titlepage}
    \centering
    {\LARGE \textbf{Proyecto Grupal \# 2} \par}
    {\LARGE Anteproyecto \par}
    \vspace{1.5cm}
    {\large José Bernardo Barquero Bonilla \\ 2023150476 \par}
    {\large Jose Eduardo Campos Salazar \\ 2023135620 \par}
    {\large Jimmy Feng Feng \\ 2023060347 \par}
    {\large Alexander Montero Vargas \\ 2023166058 \par}
    \vspace{1.5cm}
    {\Large Instituto Tecnológico de Costa Rica \par}
    {\large Escuela de Ingeniería en Computadores \par}
    {\large Curso: CE4301 - Arquitectura de Computadores I \par}
    \vspace{1.5cm}
    {\large Profesor: Dr.-Ing. Jeferson González Gómez \par}
    \vfill
    {\large 24 de octubre de 2025 \par}
\end{titlepage}

% ====== Desarrollo ======
\section{Exploración de Alternativas}

\subsection{Alternativa A: Adaptación del Proyecto LogoTEC con Microcontrolador ESP8266}

\subsubsection{Pitch del Proyecto}
El proyecto LogoTEC fue desarrollado originalmente en el curso de Compiladores e Intérpretes, con el objetivo de crear un compilador e intérprete para un lenguaje de tipo Logo capaz de generar código en C++ e interactuar con un entorno gráfico.  
La presente alternativa propone trasladar dicho sistema al ámbito físico, reemplazando la “tortuga virtual” por una tortuga robótica controlada mediante un ESP8266 ESP-12E SMT Module, que actuará como el cerebro del sistema.  
De esta forma, las instrucciones gráficas del lenguaje LogoTEC (como avanza, gira, poncolor, etc.) se traducirán en comandos físicos ejecutados por motores y actuadores reales, permitiendo visualizar en el mundo tangible los resultados del programa.

El prototipo incluirá motores para el desplazamiento de la tortuga y servomotores dedicados a levantar el lápiz y seleccionar el color de dibujo.  
Además, contará con un acelerómetro con giroscopio, conectado mediante comunicación I²C, para medir giros y orientación, y con un sensor ultrasónico encargado de detectar obstáculos y evitar colisiones.  
El sistema podrá comunicarse inalámbricamente por medio del WiFi integrado en el microcontrolador, facilitando la transmisión de datos o la interacción con el entorno de ejecución del compilador.  
De esta manera, LogoTEC se convertirá en una plataforma completa que combina software, hardware y movimiento físico bajo un mismo entorno educativo y demostrativo.

\subsubsection{Análisis de Viabilidad Técnica}
La propuesta es técnicamente factible pero presenta una complejidad considerable.  
El ESP8266, aunque potente para aplicaciones IoT, dispone de recursos limitados en memoria y pines, lo cual obliga a optimizar el código generado y adaptar la comunicación serial desde el compilador.  
La conexión entre el entorno de desarrollo (en C++ con Qt y ANTLR4) y el microcontrolador requeriría un protocolo de comunicación serial robusto (por UART) y la creación de un firmware específico para interpretar los comandos LogoTEC.  
El principal riesgo técnico radica en la adaptación del lenguaje y del flujo de compilación a un entorno embebido, además de las limitaciones de depuración en tiempo real del microcontrolador.

\subsubsection{Estimación de Esfuerzo}
La implementación de esta alternativa implicaría una fase de diseño y comunicación entre módulos más prolongada que otras opciones, ya que sería necesario integrar el compilador LogoTEC con el microcontrolador ESP8266 ESP-12E y adaptar la lógica de control a nivel de firmware.  
El tiempo estimado para lograr una integración funcional entre el compilador y el hardware sería de aproximadamente 3 a 4 semanas de trabajo intensivo, considerando las etapas de pruebas, depuración de comunicación UART y validación de movimiento físico.

En cuanto al costo, se presenta a continuación un desglose de los componentes necesarios, tomando en cuenta precios obtenidos de tiendas locales y materiales previamente disponibles en el laboratorio del grupo:

\begin{itemize}
    \item \textbf{ESP8266 ESP-12E SMT Module:} \$5.95
    \item \textbf{Servomotores (x2):} \$11.90 (\$5.95 c/u)
    \item \textbf{Giroscopio con Acelerómetro:} \$6.95
    \item \textbf{Sensor ultrasónico:} \$5.95
    \item \textbf{Módulo Expander I2C GPIO:} \$9.95
    \item \textbf{Módulo USB a TTL (UART):} \$8.50
    \item \textbf{Componentes pasivos (resistencias, capacitores, cables):} \$7.50
    \item \textbf{Alimentación (batería y cargador):} \$14.95
    \item \textbf{Impresión 3D de llantas y chasis:} 50 colones/gramo, estimado en 400 g $\approx$ 20\,000 colones ($\approx\$39.84$)
    \item \textbf{Motores DC (x2) y Driver L298:} ya disponibles
\end{itemize}

El costo total estimado asciende a:
\[
\text{Costo total} = 5.95 + 11.90 + 6.95 + 5.95 + 9.95 + 8.50 + 7.50 + 14.95 + 39.84 = \textbf{\$111.49}
\]

Aplicando el tipo de cambio del 31 de octubre de 2025 (1\,USD = 502.01\,CRC), se obtiene un costo aproximado de:

\[
111.49 \times 502.01 \approx \textbf{55\,980 colones}
\]

Este valor representa una inversión moderada en comparación con proyectos más complejos, justificando la viabilidad económica del prototipo para el alcance académico propuesto.

\subsubsection{Valor Diferencial}
El valor distintivo de esta alternativa radica en la integración de un compilador real con un sistema físico, permitiendo observar de manera tangible la traducción de instrucciones de un lenguaje de alto nivel hacia acciones mecánicas.  
Además, el proyecto aporta un valor educativo significativo, ya que por ejemplo programas como lo puede ser Micromundos (que tiene un parecido prácticamente a LogoTEC), no tienen algún componente en hardware que pueda mostrar físicamente el dibujo realizado por la persona en el software del mismo, por tanto el valor agregado en la parte educativa que da esta alternativa es un gran punto a favor en comparación a otro tipo de alternativas.

\subsection{Alternativa B: Alcancía Inteligente Basada en el Pokémon \textit{Gimmighoul}}

\subsubsection{Pitch del Proyecto}
Esta alternativa propone el desarrollo de una alcancía inteligente con forma del Pokémon Gimmighoul, personaje que representa cofres y monedas, incorporando un sistema de detección, pesaje y registro digital del dinero almacenado.  
El sistema funcionará de manera autónoma mediante un microcontrolador Mini D1 Wemos ESP8266, encargado de coordinar la lectura de una celda de carga conectada al módulo HX711 a través de comunicación SPI para determinar el peso de cada moneda insertada.  
Un sensor infrarrojo detectará el ingreso de la moneda, activando un servomotor que levantará parcialmente la tapa del cofre simulando la animación del personaje.  
Una vez medida la moneda, un segundo servomotor empujará la pieza hacia el compartimento interior, liberando la celda de carga para el siguiente registro.  
Al completarse el proceso, un módulo MP3 reproducirá un sonido característico.

El sistema contará con conectividad inalámbrica mediante WiFi, lo que permitirá enviar los datos de ahorro a una aplicación móvil dedicada.  
En esta aplicación, el usuario podrá visualizar el monto total almacenado y recibir actualizaciones automáticas cada vez que se inserte una moneda.  

\subsubsection{Análisis de Viabilidad Técnica}
La arquitectura electrónica propuesta emplea componentes de bajo costo, amplia documentación y alta disponibilidad local.  
El sistema central estará basado en el Mini D1 Wemos ESP8266, con comunicación digital tipo pseudo-SPI entre el microcontrolador y el módulo HX711 para el procesamiento de señales provenientes de la celda de carga.  
El sistema será alimentado por una batería recargable de 3.7V y 2000mAh, controlada mediante un módulo cargador TP4056 y un conversor MT3608 que eleva el voltaje a 5V, posteriormente regulado a 3.3V con un LM2596.  
El diseño se implementará en una placa perforada, optimizando la integración de módulos y asegurando una estructura ordenada.  
El nivel de complejidad es medio, al requerir sincronización entre detección de moneda, lectura de peso, control de servomotores y reproducción de audio, pero el riesgo técnico es bajo dado que los módulos cuentan con ejemplos y librerías compatibles con el entorno Arduino.

\subsubsection{Estimación de Esfuerzo}
El desarrollo de esta alternativa se estima en un periodo de 2 a 3 semanas, distribuidas entre el diseño electrónico, la programación del firmware (lectura de peso, control de servos, reproducción de audio y registro de datos), y la construcción de la estructura física del cofre mediante impresión 3D.

El siguiente desglose presenta los costos estimados de los componentes necesarios para el prototipo, utilizando precios de tiendas locales y considerando materiales ya disponibles en el laboratorio del grupo:

\begin{itemize}
    \item \textbf{Mini D1 Wemos ESP8266:} ya disponible
    \item \textbf{Servomotores SG90-180° (x2):} \$11.90 (\$5.95 c/u)
    \item \textbf{Mini Celda de Carga 100 g - Barra (TAL221):} \$16.95
    \item \textbf{Amplificador de Celda de Carga HX711:} \$8.95
    \item \textbf{MT3608 Booster:} \$2.49
    \item \textbf{LM2596 Buck Converter:} \$4.95
    \item \textbf{TP4056 Charger (USB-C Dual Protection):} \$4.95
    \item \textbf{Batería Li-Ion 3.7V 2000mAh:} \$14.95
    \item \textbf{Mini MP3 Player Module:} \$4.95
    \item \textbf{Parlante 8$\Omega$ 0.5W:} \$3.95
    \item \textbf{Componentes pasivos (resistencias, capacitores, cables, conectores):} \$7.50
    \item \textbf{Impresión 3D del cofre (400 g a 50 colones/gramo):} 20\,000 colones ($\approx\$39.84$)
\end{itemize}

El costo total estimado es:
\[
11.90 + 16.95 + 8.95 + 2.49 + 4.95 + 4.95 + 14.95 + 4.95 + 3.95 + 7.50 + 39.84 = \textbf{\$121.38}
\]

Aplicando el tipo de cambio del 31 de octubre de 2025 (1\,USD = 502.01\,CRC), el costo total aproximado es:
\[
121.38 \times 502.01 \approx \textbf{60\,900 colones}
\]

Este valor es razonable considerando la complejidad del sistema, la autonomía energética y la interacción física y digital que se busca lograr.

\vspace{0.3cm}

\subsubsection{Valor Diferencial}
El valor diferencial de esta propuesta radica en su combinación de creatividad, funcionalidad e interactividad.  
A diferencia de una alcancía convencional, este sistema permite conocer en tiempo real el monto ahorrado sin necesidad de abrir el cofre, gracias a la comunicación con una aplicación móvil desarrollada para el registro de los depósitos físicos.  
Su integración de detección por peso, animación mecánica y respuesta sonora otorga una representación física y emocional al acto de ahorrar, transformando un proceso cotidiano en una experiencia tecnológica y didáctica.

\subsection{Comparativo General}

\begin{table}[H]
\centering
\caption{Resumen comparativo entre alternativas propuestas}
\begin{tabular}{|p{4cm}|p{5cm}|p{5cm}|}
\hline
\textbf{Criterio} & \textbf{Alternativa A (LogoTEC - ESP8266 ESP-12E)} & \textbf{Alternativa B (Alcancía Gimmighoul - D1 Mini ESP8266)} \\ \hline
\textbf{Complejidad técnica} & Alta (requiere integración del compilador con el microcontrolador y manejo de firmware especializado) & Media (ensamble modular con lectura de peso, servo y audio) \\ \hline
\textbf{Costo estimado} & \$111.49 (\(\approx\) ₡55\,980) & \$121.38 (\(\approx\) ₡60\,900) \\ \hline
\textbf{Tiempo de desarrollo} & 3–4 semanas & 2–3 semanas \\ \hline
\textbf{Riesgo técnico} & Alto (sincronización software–hardware y limitaciones de comunicación) & Bajo–medio (módulos ampliamente documentados y probados) \\ \hline
\textbf{Nivel de innovación} & Alto en integración software–hardware y aplicación educativa & Alto en concepto temático, medio en complejidad técnica \\ \hline
\textbf{Impacto y demostrabilidad} & Educativo–técnico (traducción de código a ejecución física) & Interactivo y didáctico (detección de monedas, animación y sonido) \\ \hline
\end{tabular}
\end{table}

\subsubsection*{Conclusión de la Exploración}
Tras el análisis comparativo, la alternativa B representa la opción más equilibrada entre viabilidad, originalidad y esfuerzo de implementación.  
Su desarrollo integra detección de eventos, medición de peso, control de servomotores, reproducción de audio y gestión energética en un único sistema embebido.  
Además, presenta un menor riesgo técnico, tiempos de desarrollo reducidos y un costo razonable considerando su nivel de interacción y autonomía.  
Por estas razones, la alternativa B se selecciona como la propuesta final a desarrollar.

\printbibliography

\end{document}

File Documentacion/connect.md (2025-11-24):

### Conexión del ESP8266 con el amplificador HX711

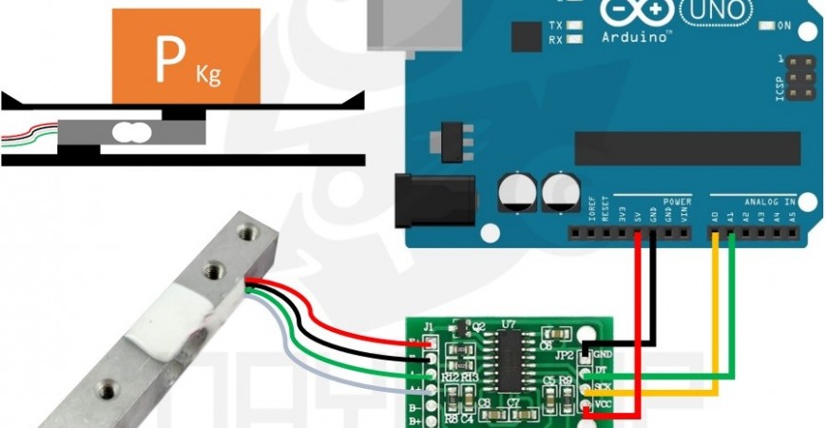
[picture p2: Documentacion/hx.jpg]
Conexión del ESP8266 con el amplificador


**Donde:**
- **DOUT → D5**  
- **CLK → D6**

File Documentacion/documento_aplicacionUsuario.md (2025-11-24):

# Aplicación de Usuario y Comunicación – GimmiCoin

## 1. Introducción

La aplicación de usuario de **GimmiCoin** permite visualizar el total ahorrado, el estado del sistema y ejecutar funciones administrativas como el reinicio del contador.  
La aplicación está construida como una **web-app embebida** dentro del microcontrolador **ESP8266**, la cual es servida a los usuarios a través de WiFi en modo **Access Point**.

---

## 2. Arquitectura General de la Aplicación

La arquitectura de comunicación sigue un modelo **cliente–servidor**, donde:

- El **ESP8266** actúa como:
  - Access Point (AP)
  - Servidor HTTP
  - Proveedor de la web-app
- El **usuario** accede desde:
  - Navegador móvil (Android/iOS)
  - Navegador en laptop

Diagrama de bloques:

```mermaid
flowchart TD
    A[Teléfono / Laptop Cliente Web] <--> B[ESP8266 Servidor AP]
    
    B --> C[Página principal HTML]
    B --> D[JSON de estado]
    B --> E[Panel admin Autenticación]
    B --> F[Comando RESET]
```

La app no requiere Internet: todo funciona dentro del AP generado por el robot.

---

## 3. Conexión y Topología de Red

### 3.1 Access Point

El ESP8266 crea automáticamente una red:

- **SSID:** `GimmiCoin_AP`
- **Password:** `12345678`
- **IP del robot:** `192.168.4.1`

El usuario solo debe conectarse y abrir en el navegador:

```

[http://192.168.4.1/](http://192.168.4.1/)

```

---

## 4. Interfaces de Usuario (Front-End)

La aplicación está pensada para ser una **web-app móvil** simple, rápida y ligera.

### 4.1 Página principal (`/`)

- Muestra:
  - Total de colones acumulados.
  - Peso de la última moneda.
  - Estado del sensor.
  - Indicación si la última moneda fue válida.

Ejemplo conceptual:

```

┌───────────────────────────────┐
│    GimmiCoin – Alcancía       │
│ ----------------------------- │
│ Total ahorrado: ₡350          │
│ Última moneda: 10.1 g (100₡)  │
│ Estado: listo para recibir    │
└───────────────────────────────┘

```

### 4.2 Panel administrativo (`/admin`)

- Protegido con **autenticación básica**:
  - Usuario: `admin`
  - Clave: `1234` (se recomienda cambiar)
- Permite:
  - Reset del contador
  - Forzar recarga de página
- Accede mediante botón en la interfaz o directamente:

```

[http://192.168.4.1/admin](http://192.168.4.1/admin)

```

---

## 5. Contratos de API (Especificación Formal)

Aquí se describe el protocolo exacto entre el frontend y el ESP8266.

---

### 5.1 `GET /`

**Descripción:** Página HTML principal.
**Formato:** HTML5 + CSS + texto embebido.
**Seguridad:** abierta (sin autenticación).

---

### 5.2 `GET /estado`

**Descripción:** Devuelve datos del sistema en formato JSON.
**Contenido del JSON:**

```json
{
  "total_crc": 350,
  "peso_ultimo": 10.1,
  "moneda_valida": true,
  "sensor_estado": "idle",
  "awake": true
}
```

**Códigos de retorno:**

| Código | Significado |
| --- | --- |
| 200 | OK |
| 500 | Error interno |

---

### 5.3 `GET /admin`

**Descripción:** Página HTML de administración.
**Seguridad:** Autenticación básica (Basic Auth).
**Códigos:**

| Código | Significado |
| --- | --- |
| 200 | Página admin  |
| 401 | No autorizado |

---

### 5.4 `GET /reset`

**Descripción:** Reinicia el contador a 0 y actualiza EEPROM.
**Seguridad:** protegida.
**Respuesta JSON:**

```json
{
  "status": "ok",
  "reset": true
}
```

---

## 6. Flujo de Interacción del Usuario

### 6.1 Flujo completo (humano → app → robot)

```mermaid
flowchart TD
  A[Usuario abre WiFi en el teléfono] --> B[Se conecta a GimmiCoin_AP]
  B --> C[Abre navegador y entra a 192.168.4.1]
  C --> D[Servidor entrega página principal HTML]
  D --> E[Usuario ve total ahorrado]
  E --> F[Inserta moneda en el robot]
  F --> G[Robot ejecuta pesaje, audio y limpieza]
  G --> H[Robot actualiza total en EEPROM]
  H --> I[App llama /estado en background para actualizar datos]
```

---

## 7. Diagramas de Secuencia

### 7.1 Usuario consulta estado con `/estado`

```mermaid
sequenceDiagram
    participant User as Navegador Web
    participant AP as ESP8266 (AP)
    participant FW as Firmware FSM

    User->>AP: GET /estado
    AP->>FW: Solicitar datos de estado
    FW-->>AP: total_crc, peso_ultimo, moneda_valida
    AP-->>User: JSON con estado
    User->>User: Actualiza pantalla
```

---

### 7.2 Reinicio de contador desde panel admin

```mermaid
sequenceDiagram
    participant Admin as Usuario (Admin)
    participant AP as ESP8266 WebServer
    participant EEPROM as Memoria Persistente

    Admin->>AP: GET /reset (Basic Auth)
    AP->>EEPROM: escribir total=0
    EEPROM-->>AP: operación completada
    AP-->>Admin: { "status": "ok", "reset": true }
```

---

## 8. Lógica del Cliente Web

### 8.1 Polling periódico

La página principal ejecuta una función JavaScript ligera que consulta el endpoint `/estado` cada 100–300 ms:

```javascript
setInterval(() => {
  fetch('/estado')
    .then(response => response.json())
    .then(data => actualizarPantalla(data));
}, 200);
```

Esto permite:

* Actualizar el total en tiempo real.
* Mostrar el peso de la última moneda.
* Indicar si hubo error o moneda incorrecta.

---

## 9. Seguridad de la Aplicación

### Riesgos mitigados:

* **Basic Auth** para funciones administrativas.
* SSID y contraseña configurados para evitar conexiones ajenas.
* Validación del firmware para prevenir montos negativos o JSON inválido.
* Desconexión automática tras estar en *deep sleep*.

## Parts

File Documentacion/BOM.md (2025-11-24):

# Bill of Materials (BOM) – Proyecto GimmiCoin  

---

## 1. Introducción

El siguiente documento detalla la **lista de materiales** utilizados en la construcción del robot ―alcancía inteligente― **GimmiCoin**, correspondiente al diseño actualizado del sistema:

- Microcontrolador ESP8266 (D1 Mini)
- Sensor de contacto
- Celda de carga TAL221 + HX711
- Motor DC + etapa de potencia 2N2222 + diodo flyback
- DFPlayer Mini + parlante
- Webserver embebido
- Powerbank 5V
- Montaje final en **tarjeta perforada**

Todos los precios están actualizados a colones costarricenses (CRC).

---

## 2. Lista de materiales completa

| # | Componente | Cantidad | Precio unitario (USD) | Precio unitario (CRC) | Proveedor | Notas |
|---|---|---|---|---|---|---|
| 1 | D1 Mini ESP8266 | 1 | $3.90 | ₡2 000 | AliExpress | Control principal |
| 2 | Celda de carga TAL221 (100g) | 1 | $3.50 | ₡1 800 | AliExpress | Sensor de pesaje |
| 3 | Módulo HX711 | 1 | $1.20 | ₡650 | AliExpress | ADC 24 bits para balanza |
| 4 | Motor DC 3–6V | 1 | $1.00 | ₡520 | Electrónica Kapro | Actuador para limpieza |
| 5 | Transistor 2N2222 | 1 | $0.10 | ₡50 | Electrónica Kapro | Etapa de potencia |
| 6 | Diodo flyback 1N4148 o 1N4007 | 1 | $0.05 | ₡30 | Electrónica Kapro | Protección del motor |
| 7 | Resistencia 10 kΩ (sensor contacto) | 1 | $0.05 | ₡30 | Electrónica Kapro | Pull-down |
| 8 | Resistencia 1 kΩ (DFPlayer RX) | 1 | $0.05 | ₡30 | Electrónica Kapro | Protección UART |
| 9 | DFPlayer Mini | 1 | $2.50 | ₡1 300 | AliExpress | Sonido del Gimmighoul |
| 10 | Parlante 8Ω 0.5W | 1 | $1.00 | ₡520 | AliExpress | Salida de audio |
| 11 | Powerbank 5V 2000–5000 mAh | 1 | $5.00 | ₡2 600 | Walmart / Electrónica | Fuente de energía |
| 12 | Tarjeta perforada | 1 | $1.00 | ₡520 | Electrónica Kapro | Montaje final obligatorio |
| 13 | Cables Dupont / cable sólido | 20 | $0.05 | ₡30 c/u | Electrónica Kapro | Conexiones |
| 14 | Protuberancias / separadores plásticos | 4 | $0.10 | ₡50 | Electrónica Kapro | Aislamiento mecánico |
| 15 | Tornillería M3 / tuercas | 6 | $0.10 | ₡50 | Ferretería | Fijación de celda/motor |
| 16 | Cinta doble adhesiva 3M | 1 | $1.00 | ₡520 | Oficentro | Montaje mecánico |
| 17 | Caja / estructura Gimmighoul (impresión 3D o manual) | 1 | $4.00 | ₡2 000 | Local / impresión | Envoltura física |

---

## 3. Costos totales

### 3.1 Total en USD  
Suma de todos los componentes:

**≈ $29.00**

### 3.2 Total en CRC  
Conversión usando **₡520 por dólar**:

**≈ ₡15 080**

(El valor puede variar levemente según proveedor y stock.)

---

## 4. Notas importantes

1. **No se usan servos ni sensores IR**, por lo que fueron removidos del BOM original.  
2. El sistema utiliza **solo un motor DC**, mediante un transistor en modo conmutación.  
3. La alimentación se simplifica notablemente con el uso de una **powerbank**, eliminando cargadores LiPo, boost, buck y baterías Li-ion.  
4. El BOM incluye componentes indispensables no considerados originalmente:  
   - resistencias  
   - diodo flyback  
   - tarjeta perforada  
5. La estructura física puede imprimirse en 3D o construirse manualmente.  

---

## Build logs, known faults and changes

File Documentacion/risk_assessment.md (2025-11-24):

# Risk Assessment – Proyecto GimmiCoin  

---

## 1. Objetivo del Análisis de Riesgos

Este documento identifica, valora y propone estrategias de mitigación para los riesgos técnicos relacionados con el desarrollo del sistema **GimmiCoin**, una alcancía inteligente basada en ESP8266, sensor de contacto, celda de carga + HX711, motor DC, DFPlayer Mini y comunicación mediante aplicación web.

El análisis considera:

- **Probabilidad (P):** frecuencia esperada del riesgo (1–3).  
- **Impacto (I):** severidad potencial sobre el proyecto (1–3).  
- **Severidad total (S = P × I):**  
  - 1–3 → Bajo  
  - 4–6 → Medio  
  - 7–9 → Alto  

---

## 2. Matriz de Riesgos Actualizada

| **ID** | **Tipo** | **Descripción del riesgo** | **P** | **I** | **S** | **Severidad** | **Plan de mitigación** |
|---|---|---|---|---|---|---|---|
| R1 | Hardware | Ruido eléctrico generado por el motor DC afectando las lecturas del HX711. | 2 | 3 | 6 | Medio | Colocar diodo flyback, condensadores de desacoplo (470–1000 µF), y separar rutas de GND. Leer balanza solo cuando el motor esté apagado. |
| R2 | Sensores | Lecturas inestables del HX711 debido a vibraciones o mala fijación de la celda TAL221. | 3 | 3 | 9 | Alto | Montaje rígido de la celda, amortiguación mecánica, lecturas promediadas (10–12 muestras), aislamiento del motor. |
| R3 | Sensores | Rebotes del sensor de contacto que generen múltiples detecciones falsas. | 3 | 2 | 6 | Medio | ISR mínima + *debounce* por tiempo, validación de intervalo mínimo entre pulsos, filtrado software. |
| R4 | Software | Desincronización entre FSM, pesaje y activación del motor (procesamiento de múltiples monedas simultáneas). | 2 | 3 | 6 | Medio | Procesar monedas de una en una en la FSM, bloquear eventos mientras se pese, añadir banderas y estados seguros. |
| R5 | Firmware | Fallos en comunicación UART con DFPlayer (no inicia, no reproduce). | 2 | 2 | 4 | Medio | Añadir retardo inicial (≥1200 ms), verificar resistencia serie de 1 kΩ, revisar soldaduras, reintento de comandos. |
| R6 | Comunicación | Pérdida de conexión WiFi del usuario al AP durante el uso. | 1 | 2 | 2 | Bajo | Usar SoftAP estable, controlar reconexiones, minimizar peso de páginas HTML. |
| R7 | Alimentación | Caídas de tensión al activar el motor si la powerbank no entrega suficiente corriente. | 2 | 3 | 6 | Medio | Usar powerbank ≥2 A, añadir condensadores de reserva, cables cortos y gruesos, pruebas de carga con motor activo. |
| R8 | Integración | Espacio reducido dentro del Gimmighoul para acomodar perforada, cables, motor y balanza. | 3 | 2 | 6 | Medio | Organizar cableado, usar conectores desmontables, modelar compartimentos, fijar electrónica en capas. |
| R9 | Firmware | Escrituras excesivas en EEPROM reduciendo su vida útil. | 2 | 2 | 4 | Medio | Implementar escritura diferida por timeout (12 s sin monedas), mantener el total en RAM durante operación. |
| R10 | Aplicación web | Fallos en endpoints `/reset` o `/estado` bajo carga o múltiples clientes. | 1 | 2 | 2 | Bajo | Manejar correctamente respuestas JSON, sanitizar inputs, priorizar FSM sobre webserver. |
| R11 | Medición | Error en calibración del peso que cause clasificación incorrecta de monedas. | 3 | 3 | 9 | **Alto** | Calibración con pesos reales, tablas de referencia, verificación después del ensamblaje final, pruebas repetitivas. |
| R12 | Pruebas | Dificultad para reproducir condiciones reales de uso bajo tiempo limitado. | 2 | 2 | 4 | Medio | Crear un plan de pruebas secuenciales (sensor, balanza, motor, audio, FSM, web), registrar resultados en video. |

---

## 3. Análisis Global de Riesgos

- **Total de riesgos identificados:** 12  
- **Distribución por severidad:**  
  - **2 riesgos altos (R2, R11)**  
  - **8 riesgos medios**  
  - **2 riesgos bajos**

### Riesgos críticos
1. **R2 – Vibración y mala fijación de celda de carga (ALTO)**  
   Puede causar lecturas inestables que afectan toda la clasificación.

2. **R11 – Calibración del peso incorrecta (ALTO)**  
   Un error en calibración hace que el robot registre monedas equivocadas o inconsistentes.

Ambos riesgos afectan directamente el propósito del proyecto (clasificación por peso).

### Riesgos importantes (medios)
- Ruido del motor (R1)  
- Rebotes del sensor (R3)  
- Sincronización FSM–motor–balanza (R4)  
- Caídas de alimentación (R7)  
- Integración física (R8)

Todos estos se han observado durante el desarrollo y requieren verificación final cerca del prototipo terminado.

### Riesgos menores
- Pérdida WiFi ocasional (R6)  
- Problemas en página web o JSON (R10)  
- Sobreescritura de EEPROM (R9)  

Estos son simples de mitigar con pruebas y ajustes menores.

---

## 4. Estrategias generales de mitigación

1. **Pruebas incrementales por módulos**  
   - Sensor → Balanza → Motor → DFPlayer → Web → FSM.  
   - Nunca integrar piezas sin probar cada módulo por separado primero.

2. **Aislamiento eléctrico y mecánico**  
   - Condensadores grandes en 5 V y 3.3 V.  
   - Separar físicamente motor y celda.  
   - Cableado ordenado y firme.

3. **Calibración rigurosa del HX711**  
   - Usar pesos patrón o monedas reales conocidas.  
   - Hacer calibración después de integrar la mecánica final.  
   - Mantener condiciones estables durante la toma de lecturas.

4. **FSM robusta**  
   - Procesar solo una moneda a la vez.  
   - Bloquear pesos durante acciones mecánicas.  
   - Validar todas las transiciones.

5. **EEPROM con escritura diferida**  
   - Solo guardar cuando el usuario deja de insertar monedas.  
   - Reducir desgaste y evitar corrupción de datos.

6. **Simulación de uso real**  
   - Pruebas continuas insertando varias monedas rápido.  
   - Evaluar si ocurre ruido, fallos de detección, problemas con motor o pesaje.

---

## 5. Conclusión

El análisis de riesgos actualizado muestra que **GimmiCoin es técnicamente viable**, con riesgos moderados y dos riesgos críticos relacionados exclusivamente con la precisión del pesaje (vibración y calibración).  
Estos riesgos son **manejables** mediante buenas prácticas de diseño mecánico, promediado de lecturas, calibración adecuada y control temporal desde la FSM.

El resto de riesgos se mitiga adecuadamente con prueba continua, buen manejo de energía y separación de módulos.  
Con las estrategias aplicadas, el equipo puede entregar un prototipo final estable, funcional y coherente con los objetivos del curso.

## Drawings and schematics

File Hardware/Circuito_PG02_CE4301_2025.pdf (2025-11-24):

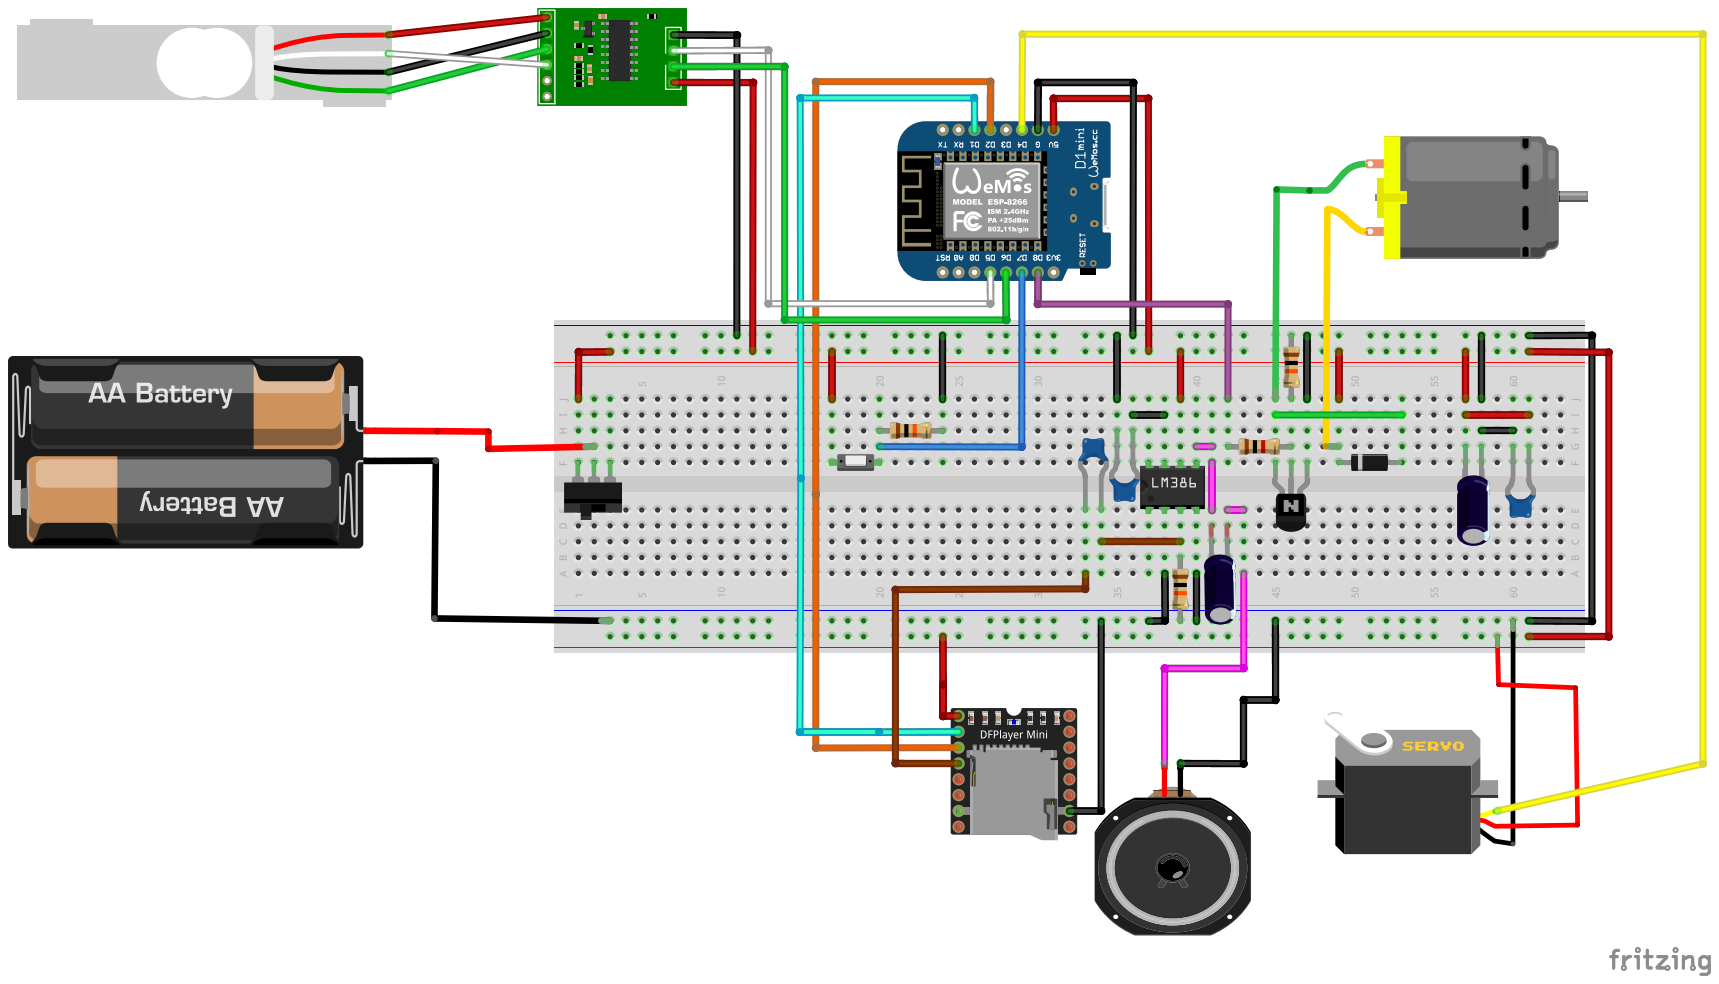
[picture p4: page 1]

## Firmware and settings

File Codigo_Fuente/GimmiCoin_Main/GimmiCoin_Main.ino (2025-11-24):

// calibracion2.ino
#if defined(__INTELLISENSE__)
#undef ARDUINO
#endif

#if defined(ARDUINO)
#include <Arduino.h>
#else
#include "arduino_stub.h"
#endif

#if defined(ARDUINO)
#include <ESP8266WiFi.h>
#include <ESP8266WebServer.h>
#else
#include "esp8266_stubs.h"
#endif

#if defined(ARDUINO)
#include <EEPROM.h>
#else
#include "eeprom_stub.h"
#endif

#define PIN_SENSOR_MONEDA   D2     // Sensor de moneda (pull-down externo)
#define PIN_SERVO           D1     // Servo SG92R
#define PIN_MOTOR           D8     // Motor DC (transistor)

#define PIN_DF_RX           D4     // DFPlayer: RX del ESP
#define PIN_DF_TX           D3     // DFPlayer: TX del ESP (con resistencia 1k)

// Pines de la balanza (HX711)
#define PIN_BALANZA_DOUT    D5     // HX711 DT
#define PIN_BALANZA_SCK     D6     // HX711 SCK

// Duraciones principales
const int T_SONIDO     = 2000;
const unsigned long PRE_MEASURE_DELAY_MS = 3000;  // 6 segundos para que deje de vibrar tras detección
const unsigned long SERVO_OPEN_SETTLE_MS = 200;  // Reducido
const unsigned long SERVO_CLOSE_SETTLE_MS = 500; // Reducido para no demorar
constexpr unsigned long DEEP_SLEEP_SETTLE_MS = 250;  // Tiempo para que la web refleje el último estado

// Valores monetarios por tipo de moneda identificado
constexpr uint32_t COIN_VALUE_10   = 10;
constexpr uint32_t COIN_VALUE_25   = 25;
constexpr uint32_t COIN_VALUE_50   = 50;
constexpr uint32_t COIN_VALUE_100  = 100;
constexpr uint32_t COIN_VALUE_500  = 500;

// Configuración de red y autenticación web
const char* WIFI_AP_SSID     = "GimmiCoin";
const char* WIFI_AP_PASSWORD = "12345678";
const char* WEB_ADMIN_USER   = "admin";
const char* WEB_ADMIN_PASS   = "1234";

ESP8266WebServer server(80);

// Persistencia del contador en EEPROM
constexpr uint16_t EEPROM_BYTES            = 16;
constexpr int      EEPROM_ADDR_COUNTER     = 0;
constexpr int      EEPROM_ADDR_MONEY       = EEPROM_ADDR_COUNTER + sizeof(uint32_t);
constexpr unsigned long EEPROM_WRITE_DELAY = 15000UL;  // Tras 15 s sin nuevas monedas reconocidas

static uint32_t coinCounter = 0;           // Conteo total persistente
static uint32_t lastPersistedCounter = 0;  // Último valor guardado en EEPROM
static uint32_t coinsSincePersist = 0;     // Conteo desde el último guardado
static bool     eepromDirty = false;       // Indica si hay datos pendientes
static unsigned long lastCoinMillis = 0;   // Última moneda detectada
static uint32_t moneyTotal = 0;            // Monto total acumulado en colones
static uint32_t lastPersistedMoney = 0;    // Último monto guardado en EEPROM
static bool pendingDeepSleep = false;      // Señala si debe entrar en deep sleep tras sincronizar
static unsigned long deepSleepScheduledAt = 0;
static bool deepSleepEngaged = false;      // Marca que ya se ejecutó la ruta de deep sleep
bool webReady = false;

// FSM principal que gobierna el flujo de la alcancía
enum class SystemState : uint8_t {
  Idle,
  MeasureCoin,
  ActuateRecognized,
  ActuateUnrecognized,
  Finalize
};

struct StateContext {
  SystemState state = SystemState::Idle;
  bool measurementDone = false;
  bool measurementStable = false;
  bool actuationDone = false;
  float lastWeight = 0.0F;
  int lastCoinValue = 0;
  unsigned long stateSince = 0;
  bool isActuating = false;  // Flag para evitar actualizar web durante actuación
  bool stabilizationMessageShown = false;  // Flag para mostrar mensaje de estabilización una vez
};

static StateContext fsmCtx;

// Declaraciones adelantadas para utilitarios web/persistencia
void startWebServer(const char* ssid, const char* password);
void handleRoot();
void handleGetStatus();
void handlePostReset();
void handlePostTare();
void handleNotFound();
void pumpServer();
void waitWithServer(unsigned long ms);
void manageEepromCommit();
void persistCounter(const char* reason, bool dueToInactivity);
uint32_t getCoinCounter();
uint32_t getMoneyTotal();
void resetCoinCounter();
bool isCoinSensorActive();
void loadCounterFromEEPROM();
const char* stateToString(SystemState state);
void transitionTo(SystemState nextState);
void processStateMachine();
void scheduleDeepSleep();
void maybeEnterDeepSleep();
void enterDeepSleepNow();

// Declaraciones adelantadas de módulos hardware
void sensorMoneda_setConteo(uint32_t value);

// Sensor de moneda
void sensorMoneda_init();
bool sensorMoneda_hayNuevaMoneda();
uint32_t sensorMoneda_getConteo();

// Motor 
void motor_init();
void motor_pulse();
void motor_start();
void motor_stop();
bool motor_isActive();
unsigned long motor_pulseDurationMs();

// Servo
void servo_init();
void servo_irAAbierto();
void servo_irACerrado();

// Sonido
void sonido_init();
void sonido_reproMoneda();

// Balanza
void balanza_init(int pin_dout, int pin_sck);
bool balanza_medirMonedaEstable(float &pesoEstable, int &tipoMoneda);
void balanza_realizarTara();

/* Function: setup
   Configura el hardware, restaura el contador persistente e inicia el servidor web.

   Params:
     - Ninguno.

   Returns:
     - void - no retorna valor.

   Restriction:
     Debe ejecutarse una sola vez al arranque del microcontrolador.
*/
void setup() {
  Serial.begin(115200);
  delay(300);

  Serial.println();
  Serial.println(F("GimmiCoin - Sistema Principal (con interfaz web)"));

  EEPROM.begin(EEPROM_BYTES);
  loadCounterFromEEPROM();

  sensorMoneda_init();
  sensorMoneda_setConteo(coinCounter);
  servo_init();
  motor_init();
  sonido_init();
  balanza_init(PIN_BALANZA_DOUT, PIN_BALANZA_SCK);

  startWebServer(WIFI_AP_SSID, WIFI_AP_PASSWORD);

  transitionTo(SystemState::Idle);

  pendingDeepSleep = false;
  deepSleepScheduledAt = 0;
  deepSleepEngaged = false;

  lastCoinMillis = millis();

  Serial.println(F("[MAIN] Inicialización completa. Esperando monedas..."));
}



/* Function: loop
   Ejecuta el ciclo principal: atiende el servidor, mide monedas y coordina actuadores.

   Params:
     - Ninguno.

   Returns:
     - void - no retorna valor.

   Restriction:
     Debe ejecutarse continuamente y no debe bloquear por largos periodos.
*/
void loop() {
  pumpServer();           // Solo actualizará web si no está actuando
  processStateMachine();
  manageEepromCommit();
  maybeEnterDeepSleep();
  delay(5);               // Cambio de waitWithServer a delay simple
}


// ---------------------------------------------------------------------------------
// Utilitarios de red, estado y EEPROM

/* Function: pumpServer
   Atiende las solicitudes HTTP pendientes del servidor y libera el watchdog.

   Params:
     - Ninguno.

   Returns:
     - void - no retorna valor.

   Restriction:
     Llamar con frecuencia para evitar timeouts en el servidor.
*/
void pumpServer() {
  // No actualizar web durante actuación para evitar mostrar valores intermedios
  if (webReady && !fsmCtx.isActuating) {
    server.handleClient();
  }
  yield();
}


/* Function: waitWithServer
   Espera un intervalo dado mientras sigue atendiendo el servidor web.

   Params:
     - ms: unsigned long - milisegundos a esperar.

   Returns:
     - void - no retorna valor.

   Restriction:
     Intervalos muy largos deben fraccionarse para no saturar la CPU.
*/
void waitWithServer(unsigned long ms) {
  unsigned long inicio = millis();
  while (millis() - inicio < ms) {
    pumpServer();
    delay(5);
  }
}

/* Function: waitWithoutServer
   Espera un intervalo dado sin atender el servidor web (para actuación).

   Params:
     - ms: unsigned long - milisegundos a esperar.

   Returns:
     - void - no retorna valor.

   Restriction:
     Solo usar durante actuación para evitar actualizar web prematuramente.
*/
void waitWithoutServer(unsigned long ms) {
  unsigned long inicio = millis();
  while (millis() - inicio < ms) {
    yield();
    delay(5);
  }
}


/* Function: stateToString
   Devuelve el nombre simbólico de un estado de la FSM para fines de depuración.

   Params:
     - state: SystemState - estado actual o destino que se desea describir.

   Returns:
     - const char* - cadena literal con la etiqueta del estado.
*/
const char* stateToString(SystemState state) {
  switch (state) {
    case SystemState::Idle:                return "IDLE";
    case SystemState::MeasureCoin:         return "MEASURE";
    case SystemState::ActuateRecognized:   return "ACTUATE_RECOGNIZED";
    case SystemState::ActuateUnrecognized: return "ACTUATE_UNRECOGNIZED";
    case SystemState::Finalize:            return "FINALIZE";
    default:                               return "UNKNOWN";
  }
}


/* Function: transitionTo
   Cambia el estado actual de la FSM y registra la marca de tiempo del cambio.

   Params:
     - nextState: SystemState - estado objetivo al que se desea transicionar.

   Returns:
     - void - no retorna valor.
*/
void transitionTo(SystemState nextState) {
  fsmCtx.state = nextState;
  fsmCtx.stateSince = millis();
  Serial.print(F("[FSM] -> "));
  Serial.println(stateToString(nextState));
}


/* Function: processStateMachine
   Ejecuta un ciclo de la máquina de estados finita que modela la alcancía.

   Params:
     - Ninguno.

   Returns:
     - void - no retorna valor.

   Restriction:
     Debe llamarse con alta frecuencia para mantener la respuesta del sistema.
*/
void processStateMachine() {
  switch (fsmCtx.state) {
    case SystemState::Idle:
      if (sensorMoneda_hayNuevaMoneda()) {
        lastCoinMillis = millis();
        pendingDeepSleep = false;
        deepSleepScheduledAt = 0;
        deepSleepEngaged = false;

        Serial.println();
        Serial.print(F("[FSM] Moneda detectada. Conteo actual = "));
        Serial.println(coinCounter);

        fsmCtx.lastWeight = 0.0F;
  fsmCtx.lastCoinValue = 0;
        fsmCtx.measurementDone = false;
        fsmCtx.measurementStable = false;
        fsmCtx.actuationDone = false;
        fsmCtx.stabilizationMessageShown = false;  // Reiniciar flag de mensaje

        transitionTo(SystemState::MeasureCoin);
      }
      break;

    case SystemState::MeasureCoin:
      // Esperar 3 segundos tras detección para que deje de vibrar
      if (millis() - fsmCtx.stateSince < PRE_MEASURE_DELAY_MS) {
        // Mostrar mensaje de estabilización una sola vez
        if (!fsmCtx.stabilizationMessageShown) {
          Serial.println(F("[FSM] Esperando 3 segundos para estabilización de vibraciones..."));
          fsmCtx.stabilizationMessageShown = true;
        }
        return; // Aún en período de espera
      }

      if (!fsmCtx.measurementDone) {
        Serial.println(F("[FSM] Iniciando medición de moneda tras estabilización."));
        fsmCtx.measurementStable = balanza_medirMonedaEstable(fsmCtx.lastWeight, fsmCtx.lastCoinValue);
        fsmCtx.measurementDone = true;

  Serial.print(F("[FSM] Unidades HX711 estabilizadas = "));
  Serial.println(static_cast<long>(fsmCtx.lastWeight));

        if (fsmCtx.lastCoinValue > 0) {
          Serial.print(F("[FSM] Valor detectado = ₡"));
          Serial.println(fsmCtx.lastCoinValue);
        } else {
          Serial.println(F("[FSM] Valor detectado inválido."));
        }

        if (!fsmCtx.measurementStable) {
          Serial.println(F("[FSM] Aviso: peso no totalmente estable (timeout)."));
        }
      }

      if (fsmCtx.lastCoinValue > 0) {
        transitionTo(SystemState::ActuateRecognized);
      } else {
        transitionTo(SystemState::ActuateUnrecognized);
      }
      break;

    case SystemState::ActuateRecognized:
      if (!fsmCtx.actuationDone) {
        fsmCtx.isActuating = true;  // Marcar inicio de actuación
        
        Serial.print(F("[FSM] Actuando moneda reconocida (₡"));
        Serial.print(fsmCtx.lastCoinValue);
        Serial.println(F(")"));

        const uint32_t coinValue = static_cast<uint32_t>(fsmCtx.lastCoinValue);
        coinCounter += 1;
        coinsSincePersist = coinCounter - lastPersistedCounter;
        moneyTotal += coinValue;
  eepromDirty = true;

        Serial.print(F("[FSM] Conteo reconocido = "));
        Serial.println(coinCounter);
        Serial.print(F("[FSM] Valor acreditado = ₡"));
        Serial.println(coinValue);
        Serial.print(F("[FSM] Total acumulado = ₡"));
        Serial.println(moneyTotal);

        switch (coinValue) {
          case COIN_VALUE_10:
            Serial.println(F("[FSM] Denominación: 10 colones"));
            break;
          case COIN_VALUE_25:
            Serial.println(F("[FSM] Denominación: 25 colones"));
            break;
          case COIN_VALUE_50:
            Serial.println(F("[FSM] Denominación: 50 colones"));
            break;
          case COIN_VALUE_100:
            Serial.println(F("[FSM] Denominación: 100 colones"));
            break;
          case COIN_VALUE_500:
            Serial.println(F("[FSM] Denominación: 500 colones"));
            break;
          default:
            Serial.println(F("[FSM] Denominación: desconocida (valor reconocido)."));
            break;
        }

        // Preparar compuerta antes de transporte
        servo_irAAbierto();
        waitWithoutServer(SERVO_OPEN_SETTLE_MS);

        // Iniciar motor y sonido tan pronto como se reconoce la moneda
        const unsigned long actionStart = millis();
        const unsigned long motorDuration = motor_pulseDurationMs();
        motor_start();
        sonido_reproMoneda();

        // Actuar sin actualizar web durante la actuación
        while (true) {
          yield(); // Solo yield, NO pumpServer para evitar actualizar web
          const unsigned long elapsed = millis() - actionStart;

          if (elapsed >= motorDuration && motor_isActive()) {
            motor_stop();
          }

          if (elapsed >= T_SONIDO && !motor_isActive()) {
            break;
          }

          delay(5);
        }

        motor_stop();

        servo_irACerrado();
        waitWithoutServer(SERVO_CLOSE_SETTLE_MS);

        lastCoinMillis = millis();
        fsmCtx.isActuating = false;  // Marcar fin de actuación

        fsmCtx.actuationDone = true;
      }

      transitionTo(SystemState::Finalize);
      break;

    case SystemState::ActuateUnrecognized:
      if (!fsmCtx.actuationDone) {
        fsmCtx.isActuating = true;  // Marcar para evitar updates durante procesamiento
        Serial.println(F("[FSM] Peso inválido o moneda desconocida. Omitiendo accionamiento."));
        lastCoinMillis = millis();
        fsmCtx.isActuating = false; // Fin inmediato ya que no hay actuación real
        fsmCtx.actuationDone = true;
      }

      transitionTo(SystemState::Finalize);
      break;

    case SystemState::Finalize:
      Serial.println(F("[FSM] Ciclo de moneda completado."));
      fsmCtx.measurementDone = false;
      fsmCtx.measurementStable = false;
      fsmCtx.actuationDone = false;
      fsmCtx.lastCoinValue = 0;
      fsmCtx.lastWeight = 0.0F;
      fsmCtx.isActuating = false;  // Asegurar que no quede marcado
      fsmCtx.stabilizationMessageShown = false;  // Limpiar flag de mensaje
      sensorMoneda_setConteo(coinCounter);
      transitionTo(SystemState::Idle);
      break;
  }
}


/* Function: manageEepromCommit
   Determina si es momento de sincronizar el contador con la EEPROM.

   Params:
     - Ninguno.

   Returns:
     - void - no retorna valor.

   Restriction:
     Debe llamarse periódicamente desde el loop principal.
*/
void manageEepromCommit() {
  const unsigned long inactivity = millis() - lastCoinMillis;

  if (deepSleepEngaged) {
    return;
  }

  if (eepromDirty) {
    if (inactivity >= EEPROM_WRITE_DELAY) {
      persistCounter("timeout", true);
    }
    return;
  }

  if (!pendingDeepSleep && inactivity >= EEPROM_WRITE_DELAY) {
    Serial.println(F("[MAIN] Inactividad prolongada sin cambios. Programando deep sleep."));
    scheduleDeepSleep();
  }
}


/* Function: persistCounter
   Escribe el contador de monedas en la EEPROM y limpia los indicadores. Puede
   opcionalmente programar la entrada a deep sleep cuando la sincronización se
   produjo por inactividad.

   Params:
     - reason: const char* - texto que describe el motivo del guardado.
     - dueToInactivity: bool - true si se invoca por timeout de inactividad.

   Returns:
     - void - no retorna valor.

   Restriction:
     Debe invocarse solo cuando eepromDirty es verdadero.
*/
void persistCounter(const char* reason, bool dueToInactivity) {
  const uint32_t counterValue = getCoinCounter();
  const uint32_t moneyValue   = getMoneyTotal();

  EEPROM.put(EEPROM_ADDR_COUNTER, counterValue);
  EEPROM.put(EEPROM_ADDR_MONEY, moneyValue);
  EEPROM.commit();

  lastPersistedCounter = counterValue;
  lastPersistedMoney   = moneyValue;
  coinsSincePersist    = 0;
  eepromDirty          = false;

  Serial.print(F("[EEPROM] Guardado contador ("));
  Serial.print(reason);
  Serial.print(F(") = "));
  Serial.println(counterValue);
  Serial.print(F("[EEPROM] Dinero acumulado = ₡"));
  Serial.println(moneyValue);

  // Solo actualizar web cuando se persiste por inactividad (timeout)
  if (dueToInactivity) {
    Serial.println(F("[EEPROM] Actualizando web tras persistencia por timeout."));
    pumpServer();
  }

  if (dueToInactivity) {
    scheduleDeepSleep();
  }
}


/* Function: getCoinCounter
   Obtiene el valor actual del contador de monedas en RAM.

   Params:
     - Ninguno.

   Returns:
     - uint32_t - total de monedas acumulado.
*/
uint32_t getCoinCounter() {
  return coinCounter;
}

uint32_t getMoneyTotal() {
  return moneyTotal;
}


/* Function: resetCoinCounter
   Restaura el contador de monedas a cero tanto en RAM como en EEPROM.

   Params:
     - Ninguno.

   Returns:
     - void - no retorna valor.

   Restriction:
     Solo debe ejecutarse tras autenticación válida desde la capa web.
*/
void resetCoinCounter() {
  sensorMoneda_setConteo(0);
  coinCounter = 0;
  lastPersistedCounter = 0;
  coinsSincePersist = 0;
  moneyTotal = 0;
  lastPersistedMoney = 0;
  eepromDirty = false;
  pendingDeepSleep = false;
  deepSleepScheduledAt = 0;
  EEPROM.put(EEPROM_ADDR_COUNTER, static_cast<uint32_t>(0));
  EEPROM.put(EEPROM_ADDR_MONEY, static_cast<uint32_t>(0));
  EEPROM.commit();
  lastCoinMillis = millis();
  Serial.println(F("[MAIN] Contador reseteado desde web."));
}


/* Function: isCoinSensorActive
   Lee el estado lógico del sensor de moneda para mostrarlo en la interfaz web.

   Params:
     - Ninguno.

   Returns:
     - bool - true si el sensor está activo, de lo contrario false.
*/
bool isCoinSensorActive() {
  return digitalRead(PIN_SENSOR_MONEDA) == HIGH;
}


/* Function: loadCounterFromEEPROM
   Recupera el contador almacenado en EEPROM y prepara los valores iniciales.

   Params:
     - Ninguno.

   Returns:
     - void - no retorna valor.

   Restriction:
     Debe invocarse después de EEPROM.begin antes de usar el contador.
*/
void loadCounterFromEEPROM() {
  uint32_t stored = 0;
  EEPROM.get(EEPROM_ADDR_COUNTER, stored);
  if (stored == 0xFFFFFFFF) {
    stored = 0;
  }
  coinCounter = stored;
  lastPersistedCounter = stored;
  Serial.print(F("[EEPROM] Conteo restaurado = "));
  Serial.println(coinCounter);
  coinsSincePersist = 0;

  uint32_t storedMoney = 0;
  EEPROM.get(EEPROM_ADDR_MONEY, storedMoney);
  if (storedMoney == 0xFFFFFFFF) {
    storedMoney = 0;
  }
  moneyTotal = storedMoney;
  lastPersistedMoney = storedMoney;

  Serial.print(F("[EEPROM] Dinero restaurado = ₡"));
  Serial.println(moneyTotal);
}


void scheduleDeepSleep() {
  if (deepSleepEngaged || pendingDeepSleep) {
    return;
  }
  pendingDeepSleep = true;
  deepSleepScheduledAt = millis();
  Serial.println(F("[POWER] Deep sleep programado tras inactividad."));
}


void maybeEnterDeepSleep() {
  if (deepSleepEngaged) {
    return;
  }

  if (!pendingDeepSleep) {
    return;
  }

  pumpServer();

  if (millis() - deepSleepScheduledAt < DEEP_SLEEP_SETTLE_MS) {
    return;
  }

  enterDeepSleepNow();
}


void enterDeepSleepNow() {
  if (deepSleepEngaged) {
    return;
  }

  Serial.println(F("[POWER] Entrando en deep sleep. Esperando nueva interrupción."));
  pendingDeepSleep = false;
  deepSleepScheduledAt = 0;
  deepSleepEngaged = true;

#if GM_USING_ARDUINO_CORE
#if defined(ARDUINO_ARCH_ESP8266)
  WiFi.forceSleepBegin();
  delay(1);
  ESP.deepSleep(0);
#else
  delay(50);
  ESP.deepSleep(0);
#endif
#else
  Serial.println(F("[POWER] Deep sleep simulado (entorno de desarrollo)."));
#endif
}


// =====================================================================================
// MÓDULO WEB - Implementación del servidor web
// =====================================================================================

/* Function: startWebServer
   Configura e inicia el servidor web en modo punto de acceso.

   Params:
     - ssid: const char* - nombre de la red Wi-Fi a crear.
     - password: const char* - contraseña de la red Wi-Fi.

   Returns:
     - void - no retorna valor.

   Restriction:
     Debe llamarse después de la inicialización de los módulos hardware.
*/
void startWebServer(const char* ssid, const char* password) {
#if defined(ARDUINO)
  WiFi.mode(WIFI_AP);
  WiFi.softAP(ssid, password);

  IPAddress IP = WiFi.softAPIP();
  Serial.print(F("[WEB] Punto de acceso iniciado. IP: "));
  Serial.println(IP);

  // Configurar rutas del servidor
  server.on("/", handleRoot);
  server.on("/status", HTTP_GET, handleGetStatus);
  server.on("/reset", HTTP_POST, handlePostReset);
  server.on("/tare", HTTP_POST, handlePostTare);
  server.onNotFound(handleNotFound);
#else
  WiFi.softAP(ssid, password);
  IPAddress IP = WiFi.softAPIP();
  Serial.print(F("[WEB] Punto de acceso simulado. IP: "));
  Serial.println(IP);

  // Configurar rutas del servidor (versión simplificada para stub)
  server.on("/", handleRoot);
  server.on("/status", handleGetStatus);
  server.on("/reset", handlePostReset);
  server.on("/tare", handlePostTare);
#endif

  server.begin();
  webReady = true;
  Serial.println(F("[WEB] Servidor web iniciado en puerto 80."));
}
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

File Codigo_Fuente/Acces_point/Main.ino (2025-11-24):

#include <ESP8266WiFi.h>
#include <ESP8266WebServer.h>
#include <EEPROM.h>


//-------------------------------------------- WEB ----------------------------------------------------------------
const char* ssid = "Pajaros_universales"; //nombre de la red
const char* password = "12345678"; //contrasenia 

const char* user = "admin"; //para posible seguridad web
const char* pass = "1234"; //posible seguridad web
ESP8266WebServer server(80);

//--------------------------------------------PINES-------------------------------------------------------------------
const int BUTTON_PIN = 4; // GPIO4 = D2



//-------------------------------------------VAR_INTER---------------------------------------------------------------

volatile unsigned int Counter = 0; //Contador de presiones, monedas, etc
volatile unsigned int MemwriteLimit = 0; //cada cuantas presiones va a escribir en memoria
volatile bool buttonPressed = false; //estado del boton

volatile unsigned long lastInterruptTime = 0; //contador para debouncer

const int memDir = 0; //direccion donde se guarda el Counter


void setup() {
  Serial.begin(115200);
  
  Start_server(ssid, password);
  
  pinMode(BUTTON_PIN, INPUT_PULLUP); // pin del boton

  EEPROM.begin(10); //reservamos 10 bytes, 
  Counter = EEPROM.read(memDir);
  Serial.print("Valor recuperado: ");
  Serial.println(Counter);

  EEPROM.begin(10); //reservamos 10 bytes, 
  Counter = EEPROM.read(memDir);
  Serial.print("Valor recuperado: ");
  Serial.println(Counter);


  attachInterrupt(digitalPinToInterrupt(BUTTON_PIN), Contar_Pulsos, FALLING); //interrupcion



}

void Write_Value_Mem(Direc, Value){
      EEPROM.write(Direc, Value);
      EEPROM.commit();
}

void loop() {
  server.handleClient(); //cada 10 pulsaciones escribe en memoria, para salvar ciclos
   if (MemwriteLimit >= 10) {
    Write_Value_Mem(memDir,Counter);
    MemwriteLimit = 0; //se resetea el counter 
    Serial.println("Guardado en EEPROM ✅");
  }



}

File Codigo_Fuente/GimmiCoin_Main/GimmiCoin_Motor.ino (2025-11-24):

// =====================================================================================
// Módulo del motor DC - Control básico de activación por pulsos
// =====================================================================================

static bool motorActivo = false;
static unsigned long motorInicioMs = 0;
const unsigned long MOTOR_DURACION_PULSO_MS = 500;  // duración nominal del impulso

void motor_init() {
  pinMode(PIN_MOTOR, OUTPUT);
  digitalWrite(PIN_MOTOR, LOW);
  Serial.println(F("[MOTOR] Motor DC inicializado."));
}

void motor_pulse() {
  motor_start();
}

void motor_start() {
  digitalWrite(PIN_MOTOR, HIGH);
  motorActivo = true;
  motorInicioMs = millis();
  Serial.println(F("[MOTOR] Motor activado."));
}

void motor_stop() {
  digitalWrite(PIN_MOTOR, LOW);
  motorActivo = false;
  Serial.println(F("[MOTOR] Motor desactivado."));
}

bool motor_isActive() {
  if (motorActivo && (millis() - motorInicioMs >= MOTOR_DURACION_PULSO_MS)) {
    motor_stop();
  }
  return motorActivo;
}

unsigned long motor_pulseDurationMs() {
  return MOTOR_DURACION_PULSO_MS;
}

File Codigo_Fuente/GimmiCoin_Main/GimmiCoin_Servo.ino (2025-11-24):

// =====================================================================================
// Módulo del servo - Control de compuerta de monedas
// =====================================================================================

#if defined(ARDUINO)
#include <Servo.h>
static Servo servoMotor;
#else
class Servo {
public:
  void attach(int) {}
  void write(int) {}
  void detach() {}
};
static Servo servoMotor;
#endif

void servo_init() {
  servoMotor.attach(PIN_SERVO);
  servo_irACerrado();
  Serial.println(F("[SERVO] Servo inicializado en posición cerrada."));
}

void servo_irAAbierto() {
  servoMotor.write(90);  // Posición abierta
  Serial.println(F("[SERVO] Posición: ABIERTO"));
}

void servo_irACerrado() {
  servoMotor.write(0);   // Posición cerrada
  Serial.println(F("[SERVO] Posición: CERRADO"));
}

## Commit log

2025-10-28 [ADD] Creación del BOM
    Se creó el BOM preliminar del proyecto. Aún hace falta ajustarlo a los precios reales y demás cosas como los componentes pasivos
2025-11-02 [UPDATE] Actualizar y reorganizar BOM para versión ESP8266
    Se actualizó la lista de materiales (BOM) para reflejar la versión basada en Mini D1 Wemos ESP8266, ajustando componentes, costos y estructura de las tablas. Se agregaron detalles sobre el tipo de ca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
2025-11-02 [ADD] risk assessment document and update BOM date
    Added a comprehensive risk assessment for the Gimmighoul Coin Collector Robot project, detailing identified risks, mitigation strategies, and overall analysis. Also updated the BOM document to includ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
2025-11-02 [ADD] reference architecture documentation
    Created Documentacion/reference_architecture.md detailing the hardware and software architecture for the Gimmighoul Coin Collector project, including design decisions, block diagrams, state machine, 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
2025-11-15 [ADD] Fritzing circuit file for PG02 project
    Added Circuito_PG02_CE4301_2025.fzz to the Hardware directory. This file contains the Fritzing schematic for the PG02 project, supporting hardware documentation and design.
    [Circuito_PG02_CE4301_2025.fzz]
2025-11-15 [UPDATE] Fritzing circuit diagram
    Revised the Circuito_PG02_CE4301_2025.fzz file with changes to the hardware schematic. Refer to the updated Fritzing file for the latest circuit layout.
    [Circuito_PG02_CE4301_2025.fzz]
2025-11-15 [UPDATE] Fritzing circuit design file
    Replaces the existing Circuito_PG02_CE4301_2025.fzz file with a new version. The update likely includes changes to the hardware schematic or layout.
    [Circuito_PG02_CE4301_2025.fzz]
2025-11-15 [ADD] [UPDATE] hardware circuit files
    Updated the Fritzing project file and added new PDF and PNG exports for Circuito_PG02_CE4301_2025. These additions provide schematic documentation and visual reference for the hardware design.
    [Circuito_PG02_CE4301_2025.fzz]
2025-11-15 [ADD] basic motor test Arduino sketch
    Introduces a simple Arduino sketch to test motor control on pin D8, toggling the motor on and off every 2 seconds.
2025-11-15 [ADD] Fritzing models for hardware components
    Added Fritzing part files for DFPlayer MINI, HX711 Weighing Sensor Module, WeMos D1 mini (no headers), load cell, and an Arduino-HX711-load-cell project. These files support hardware prototyping and 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
    [arduino-hx711-load-cell.fzz]
2025-11-15 [ADD] DFPlayer Mini sound playback test sketch
    Introduces an Arduino sketch to test DFPlayer Mini sound module functionality using SoftwareSerial on a D1 mini. The sketch initializes the module, sets the volume, plays the first track, and loops p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
2025-11-16 [ADD] servo test sketch for D1 mini
    Introduces prueba_servo.ino to test SG92R servo operation on a D1 mini using the Servo library. The sketch sweeps the servo between 0 and 180 degrees and prints status to the serial monitor.
2025-11-16 [UPDATE] servo sweep for smoother motion and constants
    Introduced constants for max angle, step size, and delay to allow smoother and more configurable servo movement. Updated sweep logic to use these constants and adjusted delays for improved operation.
2025-11-17 [ADD] main, sensor, and servo modules for GimmiCoin
    Initial commit of GimmiCoin project source files. Includes main control logic (GimmiCoin_Main.ino), coin sensor handling with debounce and interrupt (GimmiCoin_SensorMoneda.ino), and smooth servo con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
2025-11-17 [ADD] DC motor control module and integrate with main loop
    Introduces GimmiCoin_Motor.ino to handle DC motor activation, including initialization and timed pulse control. Updates GimmiCoin_Main.ino to define the motor pin, initialize the motor, and trigger t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
2025-11-17 [ADD][UPDATE] sound module integration for coin detection
    Introduces GimmiCoin_Sonido.ino to handle sound playback using DFPlayer Mini when a coin is detected. Updates GimmiCoin_Main.ino to initialize and trigger the sound module, and adjusts motor pulse du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
2025-11-17 [ADD][WARN] Integrate HX711 scale module for coin detection
    Added GimmiCoin_Balanza.ino with functions for initializing and reading from the HX711 load cell, and classifying coins by weight. Updated GimmiCoin_Main.ino to use the new balanza module for coin va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
2025-11-18 [ADD] coin sensor and motor test Arduino sketch
    Introduces prueba_moneda_motor.ino to test coin detection and motor activation using defined pins. The sketch detects a rising edge on the coin sensor and activates the motor for a set duration.
2025-11-22 [UPDATE] balanza test for improved initialization and output
    Updated the balanza test code to use clearer pin definitions, improved initialization sequence with readiness checks and tare procedure, and streamlined output to display only the measured weight in 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
2025-11-22 [ADD] coin classification test for HX711 scale
    Introduces a new Arduino sketch to classify Costa Rican coins (10, 50, 100 colones) by weight using the HX711 load cell. Includes calibration, tare, and serial output for detected coin types.
2025-11-22 [ADD] event-based coin detection with stability checks
    Enhanced the coin classification logic to detect coin placement and removal events, requiring weight stability before classification. Added auto-tare functionality to correct drift when no coin is present, and refactored thresholds and state management for more robust operation.
    [prueba_calificacion_moneda.ino]
2025-11-22 [UPDATE] coin detection and auto-tare logic
    Refactored and clarified thresholds, stability windows, and state variables for coin detection and auto-tare. Enhanced auto-tare to use a dedicated stability window near zero, improved event-based coin classification, and updated comments for better maintainability.
    [prueba_calificacion_moneda.ino]
2025-11-22 [UPDATE] DFPlayer pin mapping and improve sound handling
    Updated DFPlayer RX/TX pin assignments for consistency across main and test files. Enhanced GimmiCoin_Sonido.ino with robust initialization, error handling, and detailed status reporting for DFPlayer. Increased motor pulse duration and adjusted sound volume settings in test and main modules. Removed unused LED and scale logic from main loop for simplification.
    [GimmiCoin_Main.ino, GimmiCoin_Motor.ino, GimmiCoin_Sonido.ino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]
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2025-11-23 [ADD] stable coin measurement to balanza logic
    Introduces a blocking measurement function with stability detection in GimmiCoin_Balanza.ino, using a time window and delta threshold to ensure reliable coin classification. Updates GimmiCoin_Main.ino to use the new stable measurement, improving robustness against unstable readings and providing clearer feedback in the main loop.
    [GimmiCoin_Balanza.ino, GimmiCoin_Main.ino]
2025-11-24 [UPDATE][DELETE] servo functionality and update calibration factors
    Eliminated all servo-related code and files from the main GimmiCoin system, including GimmiCoin_Servo.ino and related function calls. Updated balance calibration factors and stability parameters in both main and test files for improved measurement accuracy. Adjusted auto-tare timing and coin classification thresholds in test scripts.
    [GimmiCoin_Balanza.ino, GimmiCoin_Main.ino, GimmiCoin_Servo.ino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]
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2025-11-24 [FIX] error en importaciones
    [GimmiCoin_Main.ino, GimmiCoin_SensorMoneda.ino, GimmiCoin_Servo.ino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]
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
